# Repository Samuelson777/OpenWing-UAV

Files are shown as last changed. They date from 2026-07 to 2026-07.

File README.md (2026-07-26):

# OpenWing-UAV

**An open, parametric, multidisciplinary UAV-wing engineering project integrating CAD, CAM, aerodynamics, structural simulation, optimisation, prototype validation, automation, and an interactive 3D web application.**

**Author:** Samuelson G
**Current development stage:** Version 0.9 digital thread
**Target release:** Version 1.0 reproducible engineering baseline







---

## Table of Contents

* [Project Overview](#project-overview)
* [Project Objectives](#project-objectives)
* [Baseline Wing Specification](#baseline-wing-specification)
* [Key Features](#key-features)
* [Development History](#development-history)
* [Engineering Workflow](#engineering-workflow)
* [CAD and Structural Architecture](#cad-and-structural-architecture)
* [Aerodynamic Analysis](#aerodynamic-analysis)
* [Structural Simulation](#structural-simulation)
* [Optimisation](#optimisation)
* [Prototype Validation](#prototype-validation)
* [Live 3D Application](#live-3d-application)
* [Tutorial Drawings](#tutorial-drawings)
* [Repository Structure](#repository-structure)
* [Available File Formats](#available-file-formats)
* [Software Requirements](#software-requirements)
* [Getting Started](#getting-started)
* [Running the GitHub Pages App](#running-the-github-pages-app)
* [SOLIDWORKS 2023 Workflow](#solidworks-2023-workflow)
* [OpenVSP Workflow](#openvsp-workflow)
* [Python Automation](#python-automation)
* [Validation and Reproducibility](#validation-and-reproducibility)
* [Known Limitations](#known-limitations)
* [Project Status](#project-status)
* [Conclusion](#conclusion)
* [Future Enhancements](#future-enhancements)
* [Roadmap](#roadmap)
* [Safety Notice](#safety-notice)
* [Contributing](#contributing)
* [Citation](#citation)
* [License](#license)
* [Author](#author)

---

## Project Overview

OpenWing-UAV is an open-source engineering project focused on the complete digital development of a modular uncrewed-aircraft wing.

The project begins with a parametric aerodynamic layout and progressively integrates:

* Airfoil generation
* Wing planform design
* Dihedral and washout
* Internal spars and ribs
* Modular wing-joiner architecture
* Aileron and servo installation
* CAD and neutral-file generation
* CAM preparation
* OpenVSP and aerodynamic modelling
* Static structural analysis
* Root-joint and contact analysis
* Modal and buckling studies
* Fatigue and nonlinear-analysis planning
* Multidisciplinary optimisation
* Prototype proof and ultimate testing
* FEA-to-experiment correlation
* Repository automation
* Interactive browser-based 3D visualisation

The project is intended to demonstrate a complete aerospace engineering workflow that can be developed on a home PC and shared through an open-source GitHub repository.

---

## Project Objectives

The primary objectives of OpenWing-UAV are to:

1. Develop a modular UAV wing using a traceable parametric design process.
2. Connect aerodynamic geometry with internal structural architecture.
3. Produce reviewable CAD, neutral geometry, drawings, and manufacturing files.
4. Transfer aerodynamic loads into structural simulation cases.
5. Evaluate strength, displacement, buckling, vibration, joints, and control-system loads.
6. Optimise the design for mass, stiffness, stability, and manufacturability.
7. Define a safe and measurable physical-validation programme.
8. Automate repository validation, manifests, dashboards, and documentation.
9. Present the entire project through an interactive GitHub Pages application.
10. Establish a reusable framework for future UAV and aerospace projects.

---

## Baseline Wing Specification

| Parameter | Value |
| --- | ---: |
| Aircraft mass | 2.5 kg |
| Full wing span | 1,200 mm |
| Semi-span | 600 mm |
| Root chord | 240 mm |
| Tip chord | 160 mm |
| Wing area | 0.240 m² |
| Aspect ratio | 6.0 |
| Taper ratio | 0.667 |
| Airfoil | NACA 4412 |
| Dihedral | 3° per half-wing |
| Midspan washout | −1° |
| Tip washout | −2° |
| Cruise speed | 15 m/s |
| Positive limit load | +3.5 g |
| Negative limit load | −1.5 g |
| Ultimate load factor | 1.5 |
| Positive ultimate half-wing load | 64.356 N |
| Negative ultimate half-wing load | 27.581 N |

### Coordinate System

The primary SOLIDWORKS coordinate convention is:

```text
X-axis: spanwise
Y-axis: chordwise
Z-axis: vertical
Root plane: X = 0
```

---

## Key Features

### Parametric Geometry

* NACA 4412 airfoil generation
* Root, midspan, and tip airfoil profiles
* Tapered wing planform
* Equation-driven chord variation
* 3° dihedral
* Progressive washout
* Quarter-chord twist reference
* Configurable span, chord, and structural dimensions

### Internal Structure

* Main spar at approximately 30% chord
* Rear spar at approximately 70% chord
* Upper and lower spar caps
* Multiple structural rib stations
* Root support ribs
* Root web doubler
* Joiner box
* Rear anti-rotation pin
* Skin shell
* Servo bay
* Wiring channel
* Removable tip architecture

### Control System

* Outboard aileron
* Three hinge stations
* Servo tray
* Servo-arm and control-horn relationship
* Pushrod load calculations
* Positive and negative control deflections
* Servo-stall structural load case

### Engineering Validation

* Positive ultimate load case
* Negative ultimate load case
* Gust-load screening
* Ground-handling loads
* Tip torsion
* Local skin-pressure loads
* Root contact and bearing studies
* Modal analysis
* Buckling analysis
* Fatigue planning
* Nonlinear post-buckling sensitivity
* Aileron, hinge, and servo validation

---

## Development History

### Version 0.1 — Parametric Wing Foundation

* Established project repository
* Defined baseline aircraft and wing requirements
* Generated NACA 4412 airfoil coordinates
* Created root, midspan, and tip profiles
* Established coordinate systems and modelling conventions

### Version 0.2 — External Wing Geometry

* Created wing stations
* Applied taper, dihedral, and washout
* Constructed guide curves
* Generated boundary surfaces
* Formed the aerodynamic wing envelope

### Version 0.3 — Internal Structure and Assembly

* Added main and rear spars
* Added spar caps
* Defined rib stations
* Added root support structure
* Created joiner and anti-rotation-pin architecture
* Added servo bay, hinges, wiring channel, and aileron

### Version 0.4 — Drawings and Manufacturing Preparation

* Produced manufacturing drawings
* Prepared rib and spar DXF profiles
* Developed joiner CAM concepts
* Added additive-manufacturing components
* Prepared STEP, STL, and 3MF outputs
* Added assembly and manufacturing documentation

### Version 0.5 — Aerodynamic Analysis

* Defined OpenVSP wing geometry
* Prepared VSPAERO analysis workflow
* Developed angle-of-attack sweeps
* Generated spanwise aerodynamic loads
* Added aileron-effectiveness studies
* Added XFOIL airfoil-polars workflow
* Created preliminary performance envelopes

### Version 0.6 — Structural Multiphysics Validation

* Positive and negative static analyses
* Mesh-convergence planning
* Root-interface validation
* Modal analysis
* Buckling analysis
* Rotating-excitation comparison
* Gust and handling load cases
* Fatigue mission-spectrum templates
* Aileron, hinge, and servo analysis
* Nonlinear post-buckling planning

### Version 0.7 — Optimisation and Trade Studies

* Defined design variables
* Created goals and constraints
* Separated beam, skin/rib, and root optimisation
* Added lightweight, balanced, and high-stiffness candidates
* Developed Pareto-ranking workflow
* Added manufacturing-complexity scoring
* Added uncertainty and robustness studies

### Version 0.8 — Prototype Validation

* Defined material-coupon tests
* Created spar and root-joint test plans
* Added aileron and servo tests
* Developed positive and negative proof-load procedures
* Developed sacrificial ultimate-load procedures
* Added modal-impact testing
* Added FEA-to-experiment correlation templates
* Added controlled model-updating procedures

### Version 0.9 — Digital Thread and Automation

* Created GitHub-ready repository structure
* Added CSV schema validation
* Added automated repository checking
* Added SHA-256 release manifests
* Added GitHub Actions workflows
* Added a responsive live 3D GitHub Pages application
* Added interactive aerodynamic, structural, and manufacturing views
* Added project dashboards and downloadable assets

---

## Engineering Workflow

The project follows this connected workflow:

```text
Requirements
    ↓
Parametric airfoil and planform
    ↓
External aerodynamic geometry
    ↓
Internal spars, ribs, skin, and joints
    ↓
Control-system integration
    ↓
Manufacturing drawings and neutral exports
    ↓
Aerodynamic analysis
    ↓
Structural simulation
    ↓
Optimisation
    ↓
Prototype testing
    ↓
FEA-to-test correlation
    ↓
Controlled model update
    ↓
Reproducible engineering release
```

---

## CAD and Structural Architecture

### Airfoil Stations

| Station | Spanwise position |  Chord | Dihedral rise | Twist |
| --- | ---: | -----: | ---: | ----: |
| Root | 0 mm | 240 mm | 0 mm | 0° |
| Midspan | 300 mm | 200 mm | 15.72 mm | −1° |
| Tip | 600 mm | 160 mm | 31.45 mm | −2° |

### Rib Stations

The baseline rib architecture uses stations near:

```text
0, 25, 75, 150, 225, 300, 330, 390, 450, 510, 570, 600 mm
```

### Spar Dimensions

| Component | Baseline dimension |
| --- | ---: |
| Main spar web | 1.5 mm |
| Rear spar web | 1.2 mm |
| Main spar caps | 6 × 3 mm |
| Rear spar caps | 4 × 2 mm |
| Standard ribs | 2.0 mm |
| Root ribs | 3.0 mm |
| Aileron boundary ribs | 2.5 mm |
| Wing skin | 1.0 mm |
| Aileron skin | 0.8 mm |

### Joiner System

| Component | Baseline dimension |
| --- | ---: |
| Joiner blade | 18 × 4 mm |
| Insertion length | 150 mm per half-wing |
| Full joiner length | 300 mm |
| Rear pin diameter  | 6 mm |
| Rear-pin insertion |  60 mm per half-wing |
| Joiner clearance | 0.20 mm nominal |

---

## Aerodynamic Analysis

The aerodynamic workflow includes:

* NACA 4412 profile generation
* OpenVSP geometry construction
* VSPAERO lifting-surface analysis
* Angle-of-attack sweeps
* Spanwise lift-distribution export
* Cruise-load mapping
* Aileron-effectiveness assessment
* XFOIL low-Reynolds-number polar generation
* Preliminary stall and performance estimation

Reference aerodynamic outputs include:

```text
OWU_LiftingLine_AlphaSweep.csv
OWU_LiftingLine_Cruise_SpanLoads.csv
```

The included lifting-line and potential-flow results are preliminary engineering references. They do not replace viscous CFD, wind-tunnel testing, or flight-test correlation.

---

## Structural Simulation

The structural workflow includes:

### Static Studies

* Positive ultimate manoeuvre
* Negative ultimate manoeuvre
* Positive gust
* Negative gust
* Wingtip handling
* Wingtip torsion
* Servo stall
* Aileron hinge moment
* Local skin pressure

### Local Studies

* Root joiner
* Joiner box
* Rear pin
* Adhesive interfaces
* Spar-cap and web transitions
* Hinge pins and lugs
* Servo tray and mounting bosses

### Dynamic Studies

* Unloaded modal analysis
* Prestressed modal analysis
* Bending and torsional mode classification
* Motor and propeller excitation mapping
* Blade-pass-frequency comparison

### Stability Studies

* Positive global buckling
* Negative global buckling
* Upper-skin local buckling
* Lower-skin local buckling
* Main-web buckling
* Rear-web buckling
* Imperfection sensitivity
* Nonlinear post-buckling response

Reference neutral results include:

```text
OWU_BeamFEA_PositiveUltimate.csv
OWU_BeamFEA_NegativeUltimate.csv
OWU_BeamFEA_Modal.csv
OWU_BeamFEA_PositiveUltimate.vtk
OWU_Equivalent_Wing_Beam.inp
```

These reference results are based on simplified neutral models and are not presented as completed SOLIDWORKS Simulation certification results.

---

## Optimisation

The Version 0.7 optimisation workflow divides the problem into manageable studies.

### Beam Sizing

Variables include:

* Main-web thickness
* Main-cap width
* Main-cap thickness
* Rear-web thickness
* Rear-cap width
* Rear-cap thickness

### Skin and Rib Stability

Variables include:

* Skin thickness
* Standard rib thickness
* Sparse, baseline, or dense rib layout

### Root and Joiner Sizing

Variables include:

* Joiner height
* Joiner thickness
* Joiner-box wall thickness
* Root-doubler length
* Root-doubler thickness

### Candidate Designs

Three principal candidate families are considered:

* Lightweight
* Balanced
* High-stiffness

### Optimisation Criteria

* Minimum mass
* Tip displacement
* Tip twist
* Spar strength
* Joiner strength
* Composite failure index
* Buckling load factor
* First bending frequency
* First torsional frequency
* Manufacturing complexity
* CAD rebuild success
* Uncertainty sensitivity

A Python ranking script identifies feasible and Pareto-optimal candidates.

---

## Prototype Validation

The planned physical-validation programme includes:

### Material Tests

* Skin laminate coupons
* Spar-cap coupons
* Plywood and web coupons
* Adhesive lap joints
* Printed-material orientation tests
* Hinge-bearing coupons

### Subcomponent Tests

* Main-spar four-point bending
* Root-joiner bending and torsion
* Aileron and hinge loading
* Servo-stall testing
* Hinge-cycle testing

### Full-Wing Tests

| Test | Half-wing target |
| --- | ---: |
| Positive limit proof | 42.904 N |
| Negative limit proof | 18.387 N |
| Positive ultimate | 64.356 N |
| Negative ultimate | 27.581 N |

### Modal Testing

* Impact-hammer excitation
* Accelerometer measurements
* Frequency-response functions
* First bending mode
* First torsional mode
* Damping estimates
* FEA frequency correlation

### Correlation Targets

| Measurement | Initial target |
| --- | ---: |
| Tip displacement | ≤10% error |
| Midspan displacement | ≤10% error |
| Spar-cap strain | ≤15% error |
| Tip twist | ≤15% error |
| Root rotation | ≤15% error |
| First bending frequency | ≤5% error |
| First torsional frequency | ≤7% error |

These are project-level correlation targets, not regulatory requirements.

---

## Live 3D Application

The project includes a standalone GitHub Pages application built with HTML, CSS, and JavaScript.

### Features

* Interactive 3D wing model
* Orbit, pan, and zoom
* Isometric, front, and top views
* Version timeline from v0.1 to v0.9
* External aerodynamic geometry
* Internal rib and spar structure
* Joiner and root-system visualisation
* Aileron and servo views
* Aerodynamic span-load vectors
* Structural deformation display
* Modal animation
* Optimisation comparison
* Prototype-test visualisation
* Digital-thread dashboard
* Screenshot export
* Responsive mobile layout
* Software-rendered fallback where WebGL is unavailable

### GitHub Pages Deployment

Upload the application files to the repository root or `/docs` directory.

Then configure:

```text
Repository Settings
→ Pages
→ Source: GitHub Actions
```

or:

```text
Repository Settings
→ Pages
→ Deploy from a branch
→ Branch: main
→ Folder: /docs
```

---

## Tutorial Drawings

The project includes a full A3 landscape tutorial drawing manual.

The drawing set covers:

* General arrangement
* Half-wing planform
* Dihedral and washout
* Root, midspan, and tip sections
* Structural architecture
* Rib profiles
* Main and rear spars
* Joiner and rear pin
* Aileron and hinges
* Servo installation
* Wingtip assembly
* Skin installation
* Adhesive sequence
* Manufacturing plan
* SOLIDWORKS modelling workflow
* Simulation setup
* Proof-load test fixture
* Final inspection checklist

Suggested file:

```text
OpenWing-UAV-Full-Tutorial-Drawings.pdf
```

---

## Repository Structure

```text
OpenWing-UAV/
├── .github/
│   ├── workflows/
│   ├── ISSUE_TEMPLATE/
│   └── PULL_REQUEST_TEMPLATE.md
│
├── cad/
│   ├── native-solidworks/
│   │   ├── parts/
│   │   ├── assemblies/
│   │   └── drawings/
│   ├── neutral/
│   │   ├── step/
│   │   ├── stl/
│   │   └── 3mf/
│   └── dxf/
│
├── cam/
│   ├── cnc/
│   ├── additive/
│   ├── fixtures/
│   └── setup-sheets/
│
├── simulation/
│   ├── openvsp/
│   ├── vspaero/
│   ├── xfoil/
│   ├── solidworks-fea/
│   ├── neutral-fea/
│   └── load-cases/
│
├── optimisation/
│   ├── design-variables/
│   ├── candidates/
│   ├── results/
│   └── scripts/
│
├── prototype/
│   ├── material-coupons/
│   ├── subcomponent-tests/
│   ├── proof-tests/
│   ├── ultimate-tests/
│   ├── modal-tests/
│   └── correlation/
│
├── data/
│   ├── templates/
│   └── results/
│
├── drawings/
│   ├── tutorial/
│   ├── manufacturing/
│   └── inspection/
│
├── docs/
│   ├── index.html
│   ├── assets/
│   └── downloads/
│
├── scripts/
│   ├── validation/
│   ├── geometry/
│   ├── simulation/
│   ├── optimisation/
│   └── release/
│
├── release/
├── media/
├── schemas/
├── README.md
├── ROADMAP.md
├── CHANGELOG.md
├── CONTRIBUTING.md
├── CITATION.cff
├── SECURITY.md
└── LICENSE
```

---

## Available File Formats

The project may contain or generate:

### CAD and Manufacturing

```text
.SLDPRT
.SLDASM
.SLDDRW
.STEP
.STP
.STL
.3MF
.DXF
.SVG
.PDF
```

### Aerodynamic and Simulation

```text
.vsp3
.vspscript
.inp
.vtk
.csv
.json
.txt
```

### Automation and Web

```text
.py
.js
.html
.css
.yml
.yaml
.bat
.md
```

### Important Format Note

STEP, STL, and 3MF files contain transferable geometry but do not preserve original SOLIDWORKS parametric feature history.

Native SOLIDWORKS files should be generated and saved using an installed copy of SOLIDWORKS 2023.

---

## Software Requirements

Depending on the selected workflow:

* SOLIDWORKS 2023
* SOLIDWORKS Simulation
* OpenVSP
* VSPAERO
* XFOIL
* Python 3.11 or newer
* Git
* Git LFS
* Modern web browser
* Optional CNC CAM software
* Optional slicing software for 3D printing

### Python Packages

Most repository-automation scripts use the Python standard library.

The SOLIDWORKS automation workflow may additionally require:

```bash
pip install pywin32
```

---

## Getting Started

### 1. Clone the Repository

```bash
git clone https://github.com/OWNER/OpenWing-UAV.git
cd OpenWing-UAV
```

Replace `OWNER` with the GitHub username or organisation name.

### 2. Install Git LFS

```bash
git lfs install
git lfs pull
```

### 3. Validate the Repository

```bash
python scripts/validate_repository.py
```

### 4. Generate Dashboard Data

```bash
python scripts/generate_dashboard_data.py
```

### 5. Generate the Release Manifest

```bash
python scripts/build_release_manifest.py
```

### 6. Run All Automation

```bash
make all
```

---

## Running the GitHub Pages App

The application does not require a JavaScript build system.

### Local Use

Open:

```text
index.html
```

in a modern browser.

For browsers that restrict local file loading, run a local HTTP server:

```bash
python -m http.server 8000
```

Then visit:

```text
http://localhost:8000
```

### GitHub Pages

Push the website to GitHub and enable Pages from the repository settings.

---

## SOLIDWORKS 2023 Workflow

The repository includes a Windows automation package for importing STEP files into SOLIDWORKS 2023.

The workflow can:

1. Open STEP models.
2. Run import diagnostics.
3. Save imported parts as `.SLDPRT`.
4. Build assemblies as `.SLDASM`.
5. Create third-angle drawings as `.SLDDRW`.
6. Export drawing PDFs.
7. Produce conversion logs.

Example launcher:

```text
RUN_SOLIDWORKS_2023_CONVERTER.bat
```

The conversion creates genuine SOLIDWORKS files only when executed on a Windows PC with SOLIDWORKS 2023 installed.

Imported STEP files become native imported-body features. They do not automatically recover the original sketches, equations, loft history, mates, or design intent.

---

## OpenVSP Workflow

The OpenVSP workflow includes:

* Python model generator
* AngelScript generator
* Wing planform configuration
* NACA 4412 section definition
* Dihedral and twist
* Native `.vsp3` generation
* STEP, STL, and DXF exports

Example generator files:

```text
generate_openwing_vsp.py
generate_openwing.vspscript
RUN_OPENVSP_GENERATOR.bat
```

---

## Python Automation

The project includes scripts for:

* NACA 4412 profile generation
* Root, midspan, and tip coordinate generation
* Load-band scaling
* Gust-load preparation
* Rotating-excitation mapping
* Candidate ranking
* FEA-to-test error calculation
* CSV schema checking
* Repository validation
* Dashboard-data generation
* Release-manifest generation
* SHA-256 file hashing
* SOLIDWORKS automation
* OpenVSP automation

---

## Validation and Reproducibility

The project uses the following reproducibility principles:

* Every released model receives a revision.
* Baseline inputs are never silently overwritten.
* Raw solver data remain separate from processed results.
* Numerical values include units and source descriptions.
* Failed studies are retained and documented.
* CAD, manufacturing, and analysis files remain revision-aligned.
* Release files receive SHA-256 hashes.
* CSV templates use controlled headers.
* GitHub Actions checks repository structure.
* Generated dashboard files are compared with committed versions.
* Preliminary models are not presented as certification evidence.

### Release Manifest

Run:

```bash
python scripts/build_release_manifest.py
```

This generates:

```text
release/manifest.csv
release/manifest.json
```

---

## Known Limitations

The current project has the following limitations:

1. The wing has not yet completed a full physical proof and ultimate test programme.
2. Material properties require coupon testing using the actual manufacturing process.
3. Reference aerodynamic results are not equivalent to validated viscous CFD or wind-tunnel data.
4. Neutral beam results are simplified and are not final detailed SOLIDWORKS Simulation results.
5. Imported STEP models do not preserve full parametric SOLIDWORKS history.
6. Generic CAM files must not be used without machine-specific verification.
7. Modal analysis alone does not establish flutter safety.
8. Potential-flow analysis does not accurately predict separated stall behaviour.
9. Complete-aircraft stability, propulsion, energy, and flight-control integration remain future work.
10. The design is not certified for flight or commercial operation.

---

## Project Status

| Workstream | Status |
| --- | --- |
| Baseline requirements | Complete |
| Parametric airfoil profiles | Complete |
| External wing geometry | Complete |
| Structural architecture | Complete |
| Neutral CAD generation | Complete |
| Tutorial drawings | Complete |
| Live 3D web application | Complete |
| Aerodynamic workflow | Complete |
| Reference aerodynamic outputs | Available |
| Structural simulation workflow | Complete |
| Neutral structural outputs | Available |
| Optimisation workflow | Complete |
| Prototype-test planning | Complete |
| Native SOLIDWORKS conversion workflow | Available |
| OpenVSP native generation workflow | Available |
| Material coupon testing | Not completed |
| Full detailed FEA validation | Not completed |
| Physical proof testing | Not completed |
| Modal test correlation | Not completed |
| Complete-aircraft integration | Not completed |
| Flight readiness | Not claimed |

---

## Conclusion

The OpenWing-UAV project demonstrates a complete, traceable, and multidisciplinary workflow for developing a modular uncrewed-aircraft wing from an initial aerodynamic concept to a digitally documented engineering system.

Beginning with the Version 0.1 parametric wing definition, the project progressively integrated airfoil generation, planform geometry, dihedral, washout, structural architecture, control surfaces, modular joiner systems, manufacturing preparation, aerodynamic assessment, structural simulation, optimisation, prototype-test planning, and repository automation through Version 0.9.

The baseline design uses a 1.2 m tapered wing with a NACA 4412 airfoil, 3° dihedral, −2° tip washout, internal spars and ribs, a removable joiner system, and an integrated aileron and servo arrangement. A consistent digital thread connects CAD geometry, manufacturing files, aerodynamic loads, structural load cases, modal and buckling studies, optimisation variables, test procedures, and project documentation.

A major strength of the project is that CAD, simulation, manufacturing, testing, and documentation are treated as connected engineering activities rather than isolated tasks. Aerodynamic loads feed structural studies, optimisation is constrained by strength and manufacturability, and physical tests are designed to correlate and improve the computational models.

The generated neutral CAD files, drawings, scripts, aerodynamic references, structural templates, optimisation tools, prototype-test plans, repository automation, and live 3D application provide a practical foundation for further development.

OpenWing-UAV therefore fulfils its purpose as an open-source aerospace engineering portfolio project. It demonstrates skills in parametric design, aerodynamics, structural mechanics, optimisation, digital manufacturing, experimental planning, software automation, technical documentation, data management, and interactive web development.

The current design should be regarded as a documented engineering prototype rather than a flight-certified aircraft component. Final flight-readiness decisions must follow physical material testing, detailed model validation, complete-aircraft integration, safety assessment, regulatory review, ground testing, and controlled flight testing.

---

## Future Enhancements

### 1. Fully Parametric Native SOLIDWORKS Models

Rebuild all imported neutral geometry as native SOLIDWORKS parts and assemblies using:

* Equation-driven sketches
* Design tables
* Parametric lofts
* Configurations
* Assembly mates
* Automated drawings
* BOM-linked custom properties
* Manufacturing configurations

This would preserve complete design intent and allow automatic resizing.

### 2. Higher-Fidelity Aerodynamics

Add:

* Viscous CFD
* Transition modelling
* Stall progression
* Propeller–wing interaction
* Control-surface gaps
* Ground effect
* Sideslip
* Unsteady gust response
* Wind-tunnel correlation
* Flight-pressure measurements

### 3. Composite Laminate Modelling

Define:

* Ply materials
* Ply orientations
* Stacking sequence
* Fibre volume fraction
* Cure process
* Core material
* Bond-line thickness
* Manufacturing tolerances

Apply composite failure criteria such as:

* Tsai–Wu
* Hashin
* Maximum stress
* Maximum strain
* Interlaminar shear
* Delamination screening

### 4. Detailed Joint and Adhesive Analysis

Improve:

* Joiner-box contact
* Adhesive peel modelling
* Cohesive-zone behaviour
* Pin bearing
* Clearance sensitivity
* Bolt preload
* Friction
* Progressive joint failure
* Root-rib bearing
* Hinge-lug fatigue

### 5. Aeroelasticity and Flutter

Add:

* Static divergence
* Control reversal
* Flutter-speed estimation
* Servo stiffness
* Hinge free play
* Mass balancing
* Gust response
* Motor-order excitation
* Propeller blade-pass excitation
* Aeroelastic model correlation

### 6. Complete-Aircraft Integration

Develop:

* Fuselage
* Tail surfaces
* Landing or launch system
* Propulsion
* Battery system
* Avionics
* Payload
* Cooling
* Wiring
* Maintenance access
* Complete mass properties
* Centre-of-gravity envelope

### 7. Propulsion and Energy Optimisation

Add:

* Motor selection
* Propeller matching
* Electronic speed controller sizing
* Battery sizing
* Endurance analysis
* Climb performance
* Thermal modelling
* Power reserve
* Voltage-drop analysis
* Vibration monitoring

### 8. Multidisciplinary Optimisation

Extend the current optimisation to include:

* Aerodynamic efficiency
* Structural mass
* Endurance
* Cost
* Manufacturing time
* Noise
* Reliability
* Stability
* Repairability

Possible methods include:

* Latin-hypercube sampling
* Genetic algorithms
* Bayesian optimisation
* Surrogate modelling
* Monte Carlo uncertainty analysis

### 9. Manufacturing Automation

Add:

* Validated machine-specific CNC files
* Post-processors
* Tool libraries
* Cutting layouts
* Material nesting
* Drill jigs
* Assembly fixtures
* Composite moulds
* Print profiles
* Inspection gauges
* Digital work instructions

### 10. Physical Prototype Testing

Complete:

* Material coupons
* Main-spar bending test
* Root-joiner test
* Hinge and servo tests
* Positive proof load
* Negative proof load
* Positive ultimate test
* Negative ultimate test
* Modal impact test
* FEA-to-test correlation

### 11. Hardware-in-the-Loop Testing

Integrate:

* Autopilot hardware
* Servos
* Sensors
* Communication links
* Telemetry
* Actuator limits
* Navigation software
* Failure handling
* Software-in-the-loop simulation
* Hardware-in-the-loop simulation

### 12. Flight-Test Programme

Create a controlled sequence for:

* Ground inspection
* Control checks
* Propulsion tests
* Restrained tests
* Initial low-risk flight
* Envelope expansion
* Endurance flights
* Gust testing
* Emergency-procedure validation
* Post-flight structural inspection

### 13. Safety and Regulatory Development

Add:

* Hazard analysis
* Failure-mode-and-effects analysis
* Operational risk assessment
* Maintenance intervals
* Inspection procedures
* Component life limits
* Lost-link logic
* Geofencing
* Emergency recovery
* Applicable regulatory requirements

### 14. Digital Twin

Connect real telemetry to the 3D model:

* Strain
* Vibration
* Temperature
* Battery condition
* Servo position
* Flight loads
* Fatigue accumulation
* Maintenance warnings
* Historical mission replay

### 15. Enhanced Web Application

Extend the GitHub Pages app with:

* glTF loading
* STEP-derived visual assets
* Exploded assemblies
* Section-cut tools
* Measurement tools
* Result contours
* Interactive plots
* Version comparisons
* Offline progressive-web-app installation
* Accessibility improvements

### 16. Automated Engineering Pipeline

Develop one controlled configuration file that can automatically generate:

* Airfoil profiles
* CAD parameters
* OpenVSP models
* Aerodynamic loads
* FEA inputs
* Optimisation scenarios
* Plots
* Drawings
* Documentation
* Website data
* Release manifests

### 17. Open Community Configurations

Allow contributors to submit:

* Alternative airfoils
* Different spans
* Different materials
* Alternative joiners
* Different propulsion systems
* New manufacturing processes
* Experimental results
* Additional analysis tools

All contributions should preserve common units, metadata, naming, licensing, and validation rules.

### 18. Version 1.0 Reproducible Release

Version 1.0 should contain:

* Final selected native CAD
* Released neutral CAD
* Manufacturing drawings
* Completed aerodynamic results
* Converged structural studies
* Material-property sources
* Prototype-test results
* Correlated FEA model
* Documented limitations
* Tagged release package
* Verified SHA-256 manifest

### 19. Complete Open UAV Platform

The long-term goal is to expand OpenWing-UAV into a complete modular uncrewed-aircraft development platform supporting:

* Aerospace education
* Environmental monitoring
* Mapping
* Research payloads
* Autonomous navigation
* Structural-health monitoring
* Comparative configuration studies
* Open and reproducible flight-test research

---

## Roadmap

```text
Version 1.0
Reproducible wing engineering release

Version 2.0
Complete aircraft integration

Version 3.0
Flight-test and telemetry digital thread
```

See [ROADMAP.md](ROADMAP.md) for the detailed roadmap.

---

## Safety Notice

This repository contains engineering geometry, structural calculations, test procedures, and manufacturing references.

Before manufacturing or testing:

* Verify all dimensions.
* Confirm material properties.
* Review machine settings.
* Simulate CAM outputs.
* Inspect imported CAD.
* Recalculate loads.
* Use calibrated instrumentation.
* Establish exclusion zones.
* Use remote loading for structural tests.
* Follow applicable UAV regulations.
* Obtain qualified engineering review where required.

Do not use generic NC or G-code directly on a machine without reviewing:

* Controller compatibility
* Units
* Coordinate system
* Tool length
* Feed rate
* Spindle speed
* Workholding
* Clearance
* Stock dimensions
* Emergency-stop procedure

This project does not provide certification, airworthiness approval, or permission to operate an aircraft.

---

## Contributing

Contributions are welcome in areas such as:

* CAD improvements
* Aerodynamics
* Structural analysis
* Materials
* Manufacturing
* Testing
* Automation
* Documentation
* Web development
* Data visualisation

Before submitting a pull request, include:

1. The problem or requirement.
2. The affected revision.
3. The changed assumptions.
4. Validation evidence.
5. Regenerated derived files.
6. Known limitations.

See [CONTRIBUTING.md](CONTRIBUTING.md).

---

## Citation

Citation metadata is provided in:

```text
CITATION.cff
```

Suggested citation:

```text
Samuelson G. OpenWing-UAV: An Open Parametric CAD, CAM,
Aerodynamic, Structural Validation, Optimisation, and Prototype
Testing Framework for a Modular Uncrewed-Aircraft Wing. 2026.
```

---

## License

The repository scaffold, scripts, and documentation are released under the MIT License unless otherwise stated.

See [LICENSE](https://github.com/Samuelson777/OpenWing-UAV/blob/main/LICENSE).

Before publishing third-party datasets or engineering files, confirm redistribution rights for:

* Airfoil data
* Material databases
* Standards
* CAD libraries
* Software-generated assets
* Test data
* Manufacturer specifications

---

## Author

**Samuelson G**

OpenWing-UAV is developed as an open-source aerospace engineering, research, automation, and portfolio project.

---

## Acknowledgement

This project uses concepts and workflows associated with:

* Parametric CAD
* OpenVSP
* VSPAERO
* XFOIL
* Finite-element analysis
* Composite structures
* Experimental modal analysis
* Multidisciplinary design optimisation
* GitHub Actions
* GitHub Pages
* Open engineering documentation

---

## Final Statement

OpenWing-UAV is not only a wing model. It is a complete engineering-development framework connecting requirements, geometry, analysis, manufacturing, testing, optimisation, documentation, and public communication in one traceable open-source project.

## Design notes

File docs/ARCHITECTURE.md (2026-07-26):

# Application architecture

- `index.html`: semantic application shell and accessible controls.
- `styles.css`: responsive desktop/mobile dashboard styling.
- `app.js`: minimal WebGL 2 renderer, camera, parametric geometry, analysis overlays and UI state.
- `data/app-data.js`: generated project data from CSV engineering outputs.
- `sw.js`: offline application-shell cache.
- `assets/downloads/`: downloadable engineering artefacts.

The application intentionally uses no npm build, framework, CDN or runtime dependency. GitHub Pages serves the files directly.

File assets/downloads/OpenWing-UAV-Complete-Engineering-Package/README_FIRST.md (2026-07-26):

# OpenWing-UAV Complete Engineering Package

This package combines all previously created project files with the newly generated engineering deliverables.

## Newly generated

- 32 watertight part geometries
- 35 AP203 faceted STEP files
- 35 STL files
- 35 3MF files
- 16 DXF drawings and SVG previews
- 13 generic, unverified NC files
- Right-wing and full-wing geometry assemblies
- Completed lifting-line aerodynamic result CSVs
- Completed equivalent beam-FEA static and modal results
- Neutral CalculiX/Abaqus-style input deck and VTK result
- OpenVSP scripts that generate the native `.vsp3` model and OpenVSP exports
- SOLIDWORKS COM automation that generates `.SLDPRT`, `.SLDASM`, and `.SLDDRW` files when run on Windows with SOLIDWORKS installed

## Remaining application-dependent outputs

Native SOLIDWORKS binaries and the native OpenVSP `.vsp3` file cannot be written without those installed applications. The package includes executable generator scripts for them rather than fake files. Native SOLIDWORKS Simulation databases and machine-approved G-code also require the licensed solver and actual machine/postprocessor.

Start with:

`02_GENERATED_ENGINEERING_FILES/08_DOCUMENTATION/README_FIRST.md`

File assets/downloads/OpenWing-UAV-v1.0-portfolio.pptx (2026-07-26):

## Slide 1

FINAL REPRODUCIBLE ENGINEERING RELEASE

OpenWing-UAV

A complete CAD · CAM · Aero · FEA · Optimisation · Prototype-validation digital thread for a modular UAV wing.

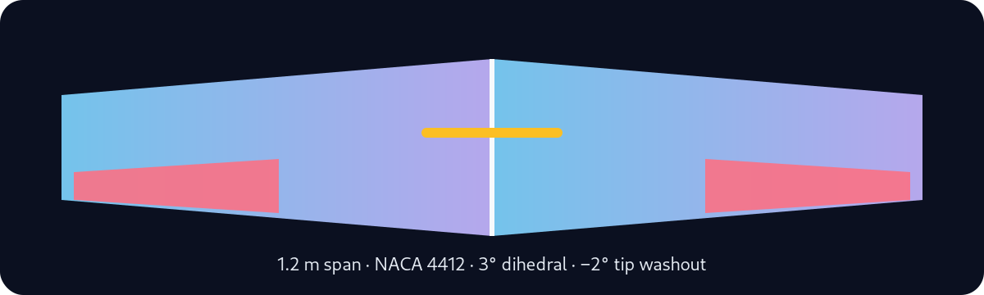
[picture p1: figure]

GitHub-ready v1.0 release framework

Home-PC feasible engineering workflow

Release gate: every claim links to evidence

Author: Samuelson G

OpenWing-UAV v1.0 · Samuelson G

01

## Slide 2

The portfolio challenge

Show credible aerospace CAD/CAM/CAE capability without needing a factory or wind tunnel.

Result: a project that demonstrates the full engineering loop, not only a CAD model.

Design depth

Parametric wing, aileron, spars, ribs, joiner, hinges and manufacturable parts.

1

Engineering proof

Loads, FEA, buckling, modal response, optimisation and test correlation.

2

Open-source credibility

Repository validation, data schemas, dashboards and release manifests.

3

OpenWing-UAV v1.0 · Samuelson G

02

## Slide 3

Digital thread architecture

Every output is linked to a source model, requirement, dataset or test.

No result is “final” unless its source data, units, coordinate system, revision, acceptance criterion and limitation are recorded.

CAD

Parametric wing

Aero

OpenVSP/XFOIL

Optimise

Pareto trades

Correlate

Model update

CAM

CNC + AM

FEA

Static + modal

Prototype

Proof + modal

Release

Manifest + site

Core rule

OpenWing-UAV v1.0 · Samuelson G

03

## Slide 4

Baseline wing specification

A compact UAV half-wing that is still rich enough for real engineering validation.

1.200 m

span

0.240 m²

area

NACA 4412

airfoil

3°

dihedral

−2°

tip washout

64.356 N

+ ultimate half-wing

27.581 N

− ultimate half-wing

6.0

aspect ratio

OpenWing-UAV v1.0 · Samuelson G

04

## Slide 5

Validation stack

The model becomes credible only when analysis and experiment agree within defined targets.

OpenVSP, VSPAERO, XFOIL, parasite drag, stall sensitivity

Static, contact, adhesive, modal, buckling, fatigue, nonlinear

Coupons, spar, root joiner, aileron, proof, ultimate, modal

Model updating, evidence matrix, independent validation case

Acceptance examples: reaction equilibrium ≤1%, displacement correlation ≤10%, first bending frequency error ≤5%, torsion ≤7%.

Aero loads

Structural FEA

Prototype tests

Correlation

OpenWing-UAV v1.0 · Samuelson G

05

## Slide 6

Repository automation

The project is packaged as a reviewable, reproducible GitHub repository.

Validated package: 71 repository files · engineering templates · GitHub Pages site · release framework

CSV schemas

Required columns for controlled evidence tables

Validation CI

Checks paths, config, CSV headers, Pages files and temp files

Dashboard data

Generates a JSON catalogue for the portfolio site

Release manifest

Creates SHA-256 hashes for every release artefact

Release gate

Blocks final claims until required evidence is complete

OpenWing-UAV v1.0 · Samuelson G

06

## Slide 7

v1.0 evidence gate

The final release separates “framework ready” from “engineering validated.”

Repository scaffold, website, validators, manifests, v1.0 checklists, release notes, presentation assets.

CAD baseline, solver outputs, coupon data, proof tests, modal results and correlated FEA model.

Only after every required matrix item points to reviewed evidence with traceable revision and units.

Honest release status is a feature: it shows discipline, not weakness.

Ready now

Requires evidence

Final claim

OpenWing-UAV v1.0 · Samuelson G

07

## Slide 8

Skills demonstrated

A single project covering the complete aerospace engineering workflow.

Portfolio takeaway: design thinking + simulation literacy + manufacturing realism + open-source discipline.

CAD

SolidWorks part, multibody, assembly, drawings

CAM

DXF, CNC routing, joiner machining, setup sheets

AM

STL/3MF, print orientation, fit coupons

Aero

OpenVSP/VSPAERO, XFOIL, performance envelope

FEA

Static, contact, buckling, modal, fatigue, nonlinear

Testing

Coupons, proof loads, modal hammer, correlation

Optimisation

Design studies, Pareto ranking, uncertainty

DevOps

GitHub Actions, Pages, manifests, schemas

OpenWing-UAV v1.0 · Samuelson G

08

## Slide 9

Path beyond v1.0

The repository is ready to become a real test-correlated engineering baseline.

Next action: upload the repository, replace OWNER placeholders, enable Pages, and begin filling the release evidence matrix.

v1.0

Populate evidence and tag reproducible release

v2.0

Integrate fuselage, empennage, propulsion and complete-aircraft stability

v3.0

Add flight-test data, telemetry processing and validated operating envelope

OpenWing-UAV v1.0 · Samuelson G

09

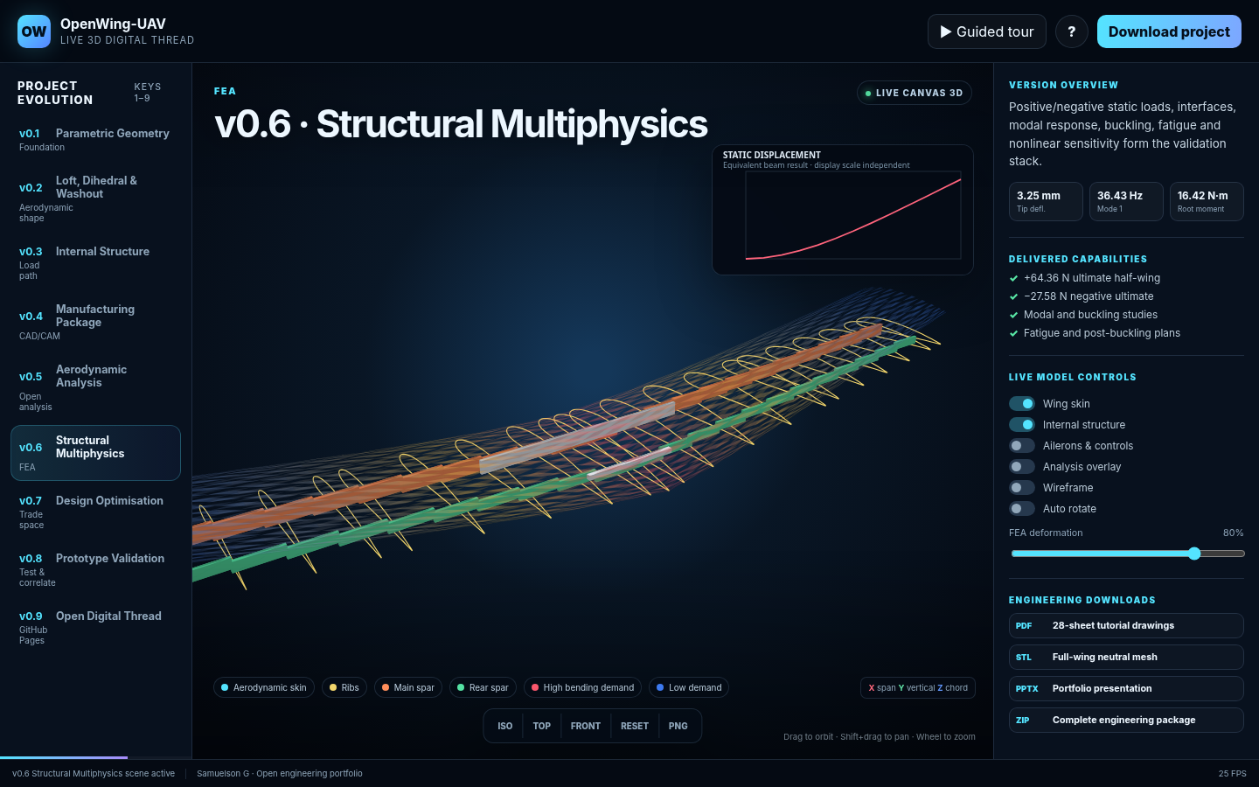
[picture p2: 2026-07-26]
assets/images/live-3d-preview.png

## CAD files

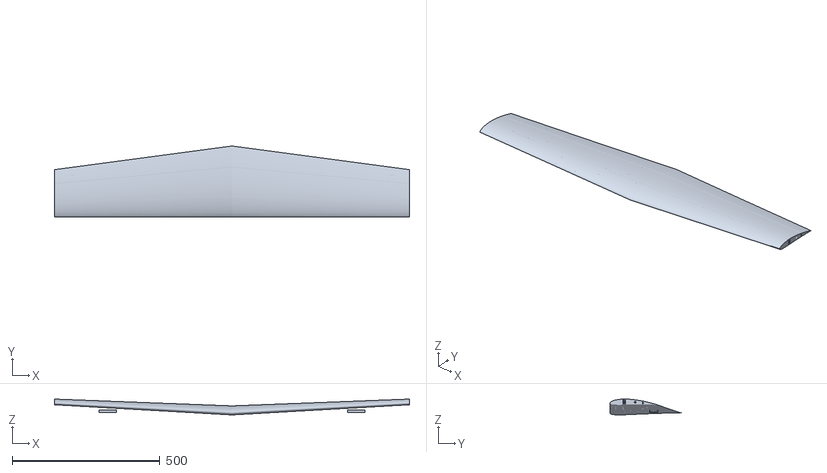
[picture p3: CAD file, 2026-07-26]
assets/downloads/OWU-1000_Full_Wing_Assembly.stl
1200.0 x 240.1 x 53.7

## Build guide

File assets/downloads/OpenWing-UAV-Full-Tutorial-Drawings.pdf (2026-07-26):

# OPENWING-UAV

# FULL TUTORIAL DRAWING MANUAL

Parametric CAD, internal structure, control system, assembly, simulation and prototype validation

# Author: SAMUELSON G

Drawing package revision A | Units: millimetres unless otherwise stated | July 2026

# Drawing index and tutorial sequence

Sheet | Drawing | Title | Purpose
01 | OWU-TUT-000 | Cover | Project identity
02 | OWU-TUT-001 | Drawing index | Navigation and conventions
03 | OWU-TUT-002 | Project baseline | Key design inputs
04 | OWU-TUT-003 | Coordinate system | SolidWorks reference setup
05 | OWU-TUT-100 | Full-wing general arrangement | Primary dimensions
06 | OWU-TUT-110 | Right half-wing layout | Stations, spars and aileron
07 | OWU-TUT-120 | Dihedral and washout | Front/section geometry
08 | OWU-TUT-130 | Airfoil sections | Root, mid and tip profiles
09 | OWU-TUT-200 | Internal structure | Exploded structural architecture
10 | OWU-TUT-210 | Root rib | Root slots and systems
11 | OWU-TUT-211 | Standard rib | Typical rib manufacture
12 | OWU-TUT-212 | Servo-bay rib | Control installation clearance
13 | OWU-TUT-220 | Spar system | Web and cap sizing
14 | OWU-TUT-230 | V-joiner and root box | Removable wing interface
15 | OWU-TUT-231 | Rear anti-rotation pin | Secondary root restraint
16 | OWU-TUT-300 | Aileron geometry | Cut, hinge and gaps
17 | OWU-TUT-310 | Hinge fitting | Pin, barrel and lugs
18 | OWU-TUT-320 | Servo bay and linkage | Actuator installation
19 | OWU-TUT-330 | Wingtip cap | Removable 50 mm tip
20 | OWU-TUT-400 | Skin and bonding | Shells and adhesive sequence
21 | OWU-TUT-410 | Assembly sequence A | Spars, ribs and root
22 | OWU-TUT-411 | Assembly sequence B | Skin, controls and closure
23 | OWU-TUT-500 | SolidWorks modelling workflow | Feature-by-feature tutorial
24 | OWU-TUT-600 | Static simulation setup | Loads, restraints and mesh
25 | OWU-TUT-610 | Modal and buckling setup | Dynamic and stability studies
26 | OWU-TUT-700 | Prototype proof-load fixture | Distributed test setup
27 | OWU-TUT-800 | Manufacturing and BOM | Parts, materials and processes
28 | OWU-TUT-900 | Inspection and release | Final checklist

## OPENWING-UAV

Drawing index

Tutorial drawing - dimensions in mm - verify before manufacture

DRAWING | SHEET
OWU-TUT-001 | 2/28
SCALE NTS | REV A
Educational engineering package. Not a certification or flight-release drawing.

# Project baseline and design intent

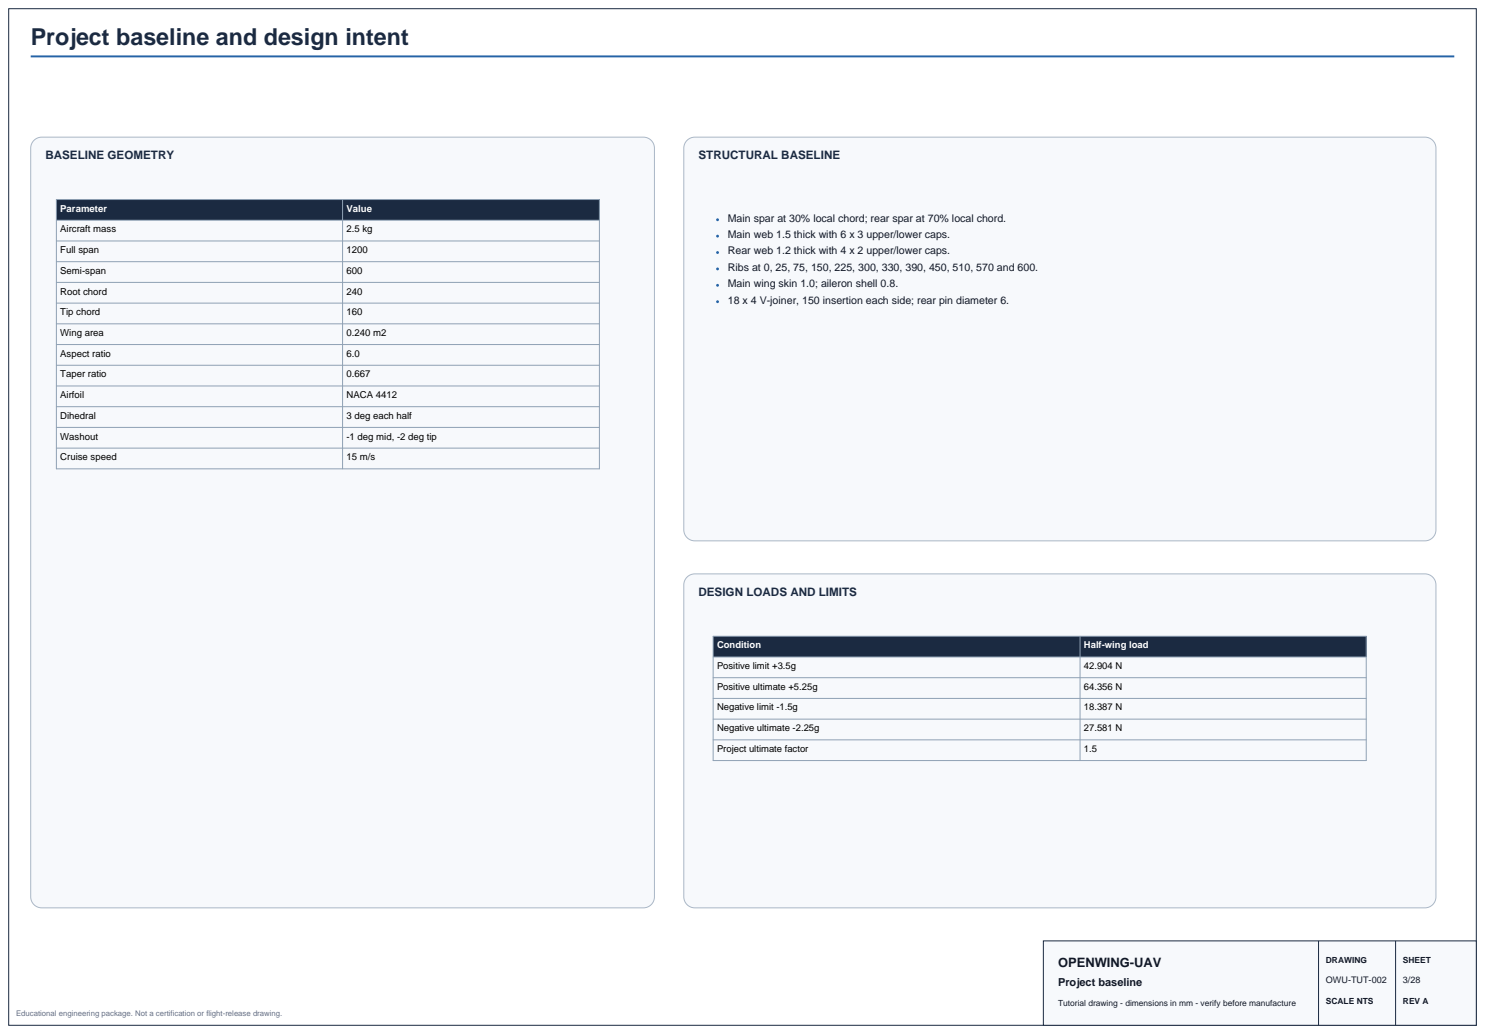
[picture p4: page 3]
BASELINE GEOMETRY; STRUCTURAL BASELINE; OPENWING-UAV; Project baseline; DRAWING; SHEET; OWU-TUT-002

Parameter | Value
Aircraft mass | 2.5 kg
Full span | 1200
Semi-span | 600
Root chord | 240
Tip chord | 160
Wing area | 0.240 m2
Aspect ratio | 6.0
Taper ratio | 0.667
Airfoil | NACA 4412
Dihedral | 3 deg each half
Washout | -1 deg mid, -2 deg tip
Cruise speed | 15 m/s

Main spar at 30% local chord; rear spar at 70% local chord.
Main web 1.5 thick with 6 x 3 upper/lower caps.
Rear web 1.2 thick with 4 x 2 upper/lower caps.
Ribs at 0, 25, 75, 150, 225, 300, 330, 390, 450, 510, 570 and 600.
Main wing skin 1.0; aileron shell 0.8.
18 x 4 V-joiner, 150 insertion each side; rear pin diameter 6.

DESIGN LOADS AND LIMITS

Condition | Half-wing load
Positive limit +3.5g | 42.904 N
Positive ultimate +5.25g | 64.356 N
Negative limit -1.5g | 18.387 N
Negative ultimate -2.25g | 27.581 N
Project ultimate factor | 1.5

# SolidWorks coordinate system and master reference planes

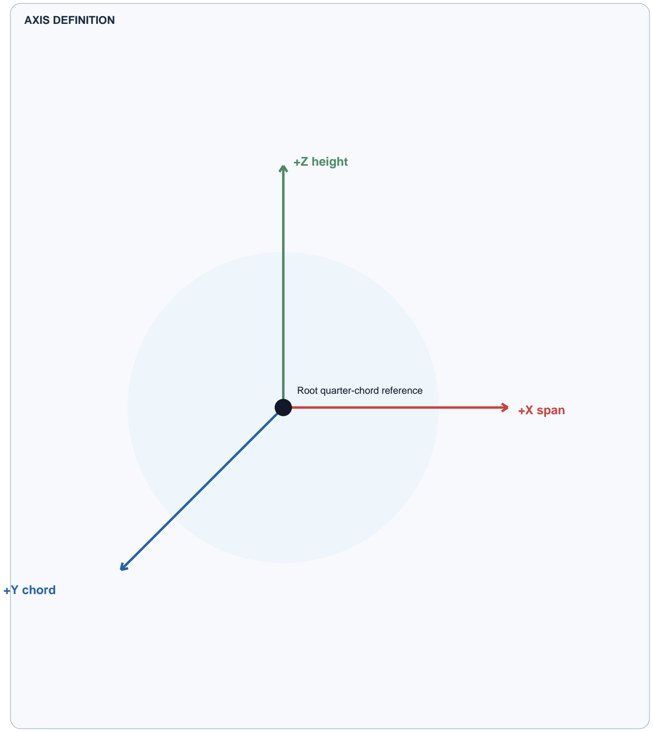
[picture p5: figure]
AXIS DEFINITION; +X span; +Z height; +Y chord; Root quarter-chord reference

### MASTER REFERENCES

Root plane: X = 0 symmetry and joiner centre.
Midspan plane: X = 300, dihedral rise 15.722, twist -1 deg.
Tip plane: X = 600, dihedral rise 31.445, twist -2 deg.
All twist rotations are about each section quarter-chord point.
Chord direction +Y points from leading edge toward trailing edge. Use named axes AX_SPAN, AX_AILERON_HINGE and AX_JOINER.

### SOLIDWORKS SETUP TUTORIAL

1. Create a new metric part and save immediately.
2. Insert planes offset 300 and 600 from the root plane.
3. Create quarter-chord sketch points on all station planes.
4. Apply 3 deg dihedral through Z offsets, then apply twist.
5. Lock station sketches to global variables before lofting.

## OPENWING-UAV

Coordinate system

DRAWING | SHEET
OWU-TUT-003 | 4/28

# Full-wing general arrangement

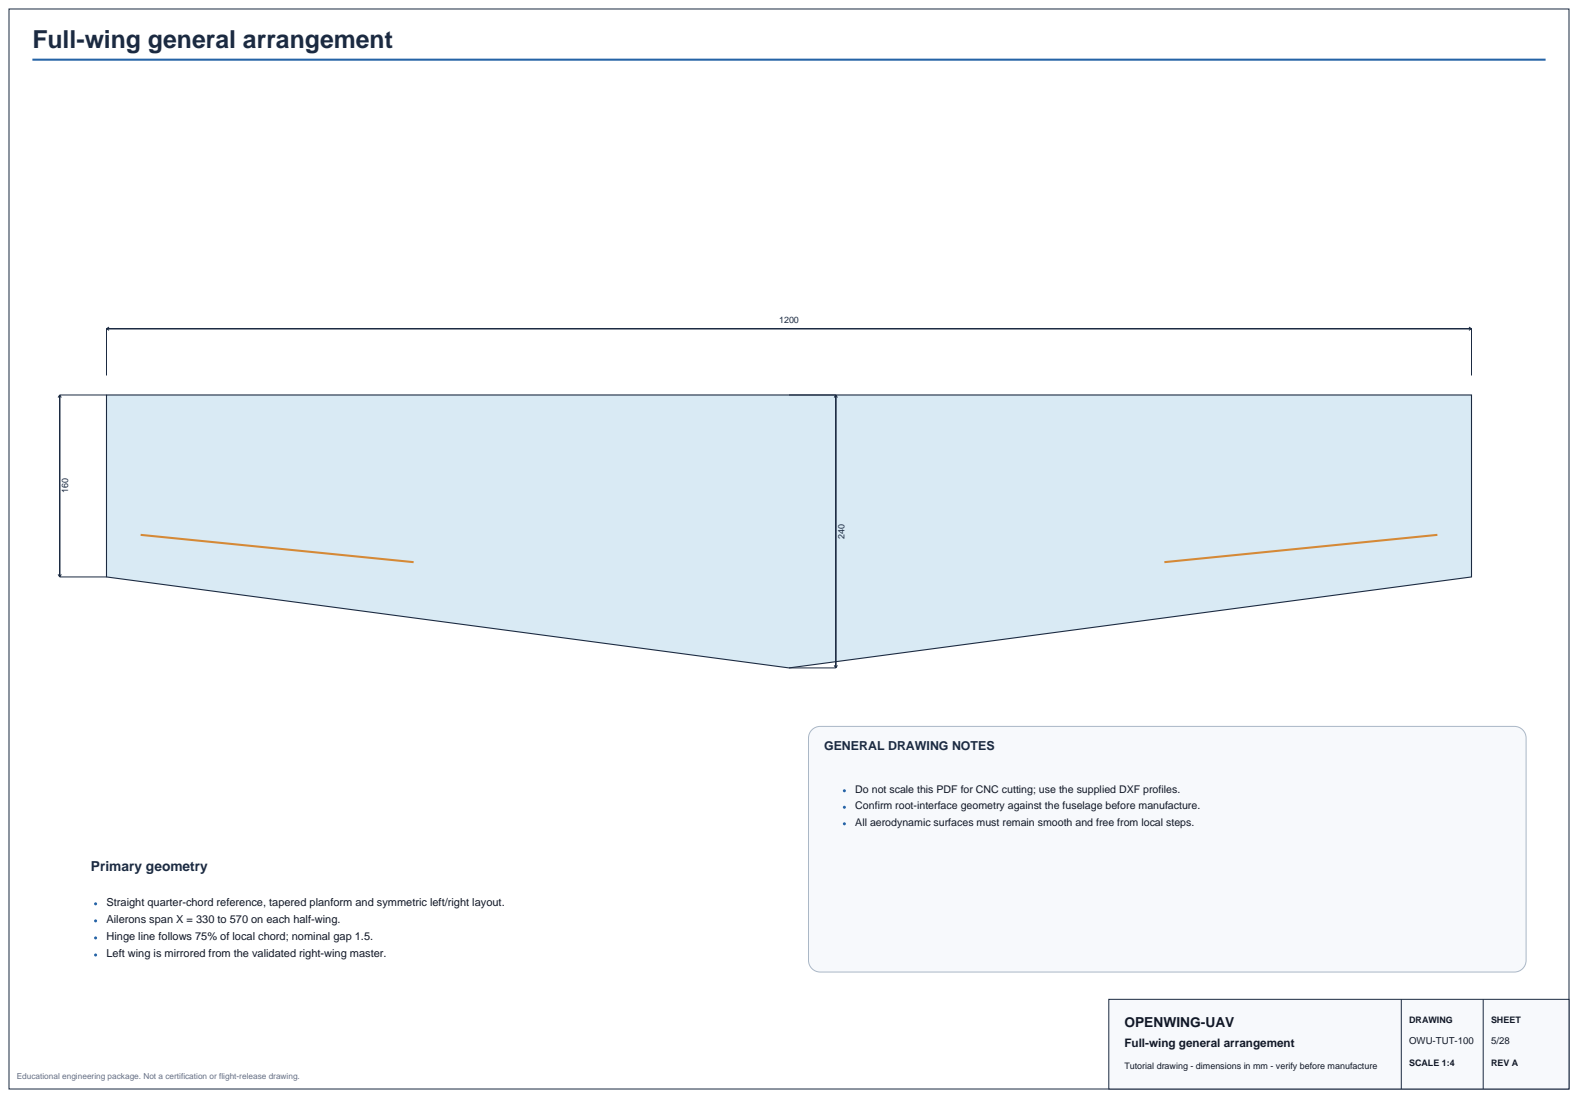
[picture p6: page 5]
Primary geometry; DRAWING; SHEET; OWU-TUT-100; SCALE 1:4; REV A

GENERAL DRAWING NOTES

Do not scale this PDF for CNC cutting; use the supplied DXF profiles.
Confirm root-interface geometry against the fuselage before manufacture.
All aerodynamic surfaces must remain smooth and free from local steps.

Straight quarter-chord reference, tapered planform and symmetric left/right layout.
Ailerons span X = 330 to 570 on each half-wing.
Hinge line follows 75% of local chord; nominal gap 1.5.
Left wing is mirrored from the validated right-wing master.

OPENWING-UAV
Full-wing general arrangement

# Right half-wing structural and station layout

0 | 25 | 75 | 150 | 225 | 300 | 330 | 390 | 450 | 510 | 570 | 600
| | | | | 600
Station X | Chord | Function
0 | 240.0 | Root rib
25 | 236.7 | Root support
75 | 230.0 | Structural
150 | 220.0 | Doubler end
225 | 210.0 | Structural
300 | 200.0 | Midspan
330 | 196.0 | Aileron boundary
390 | 188.0 | Hinge/servo
450 | 180.0 | Servo/hinge
510 | 172.0 | Aileron rib
570 | 164.0 | Aileron boundary
600 | 160.0 | Tip

### COLOUR KEY AND CONSTRUCTION

Main spar - 30% chord

Rear spar - 70% chord

Aileron hinge - 75% chord

Ribs and station planes

Make rib stations and control boundaries configuration-safe.
Preserve a minimum of 1.5 gap at aileron ends and hinge line.
Locate wiring channel through the rib neutral region, clear of spar slots.

## OPENWING-UAV

Right half-wing layout

DRAWING | SHEET
OWU-TUT-110 | 6/28
SCALE 1:2 | REV A

# Dihedral, station rise and washout

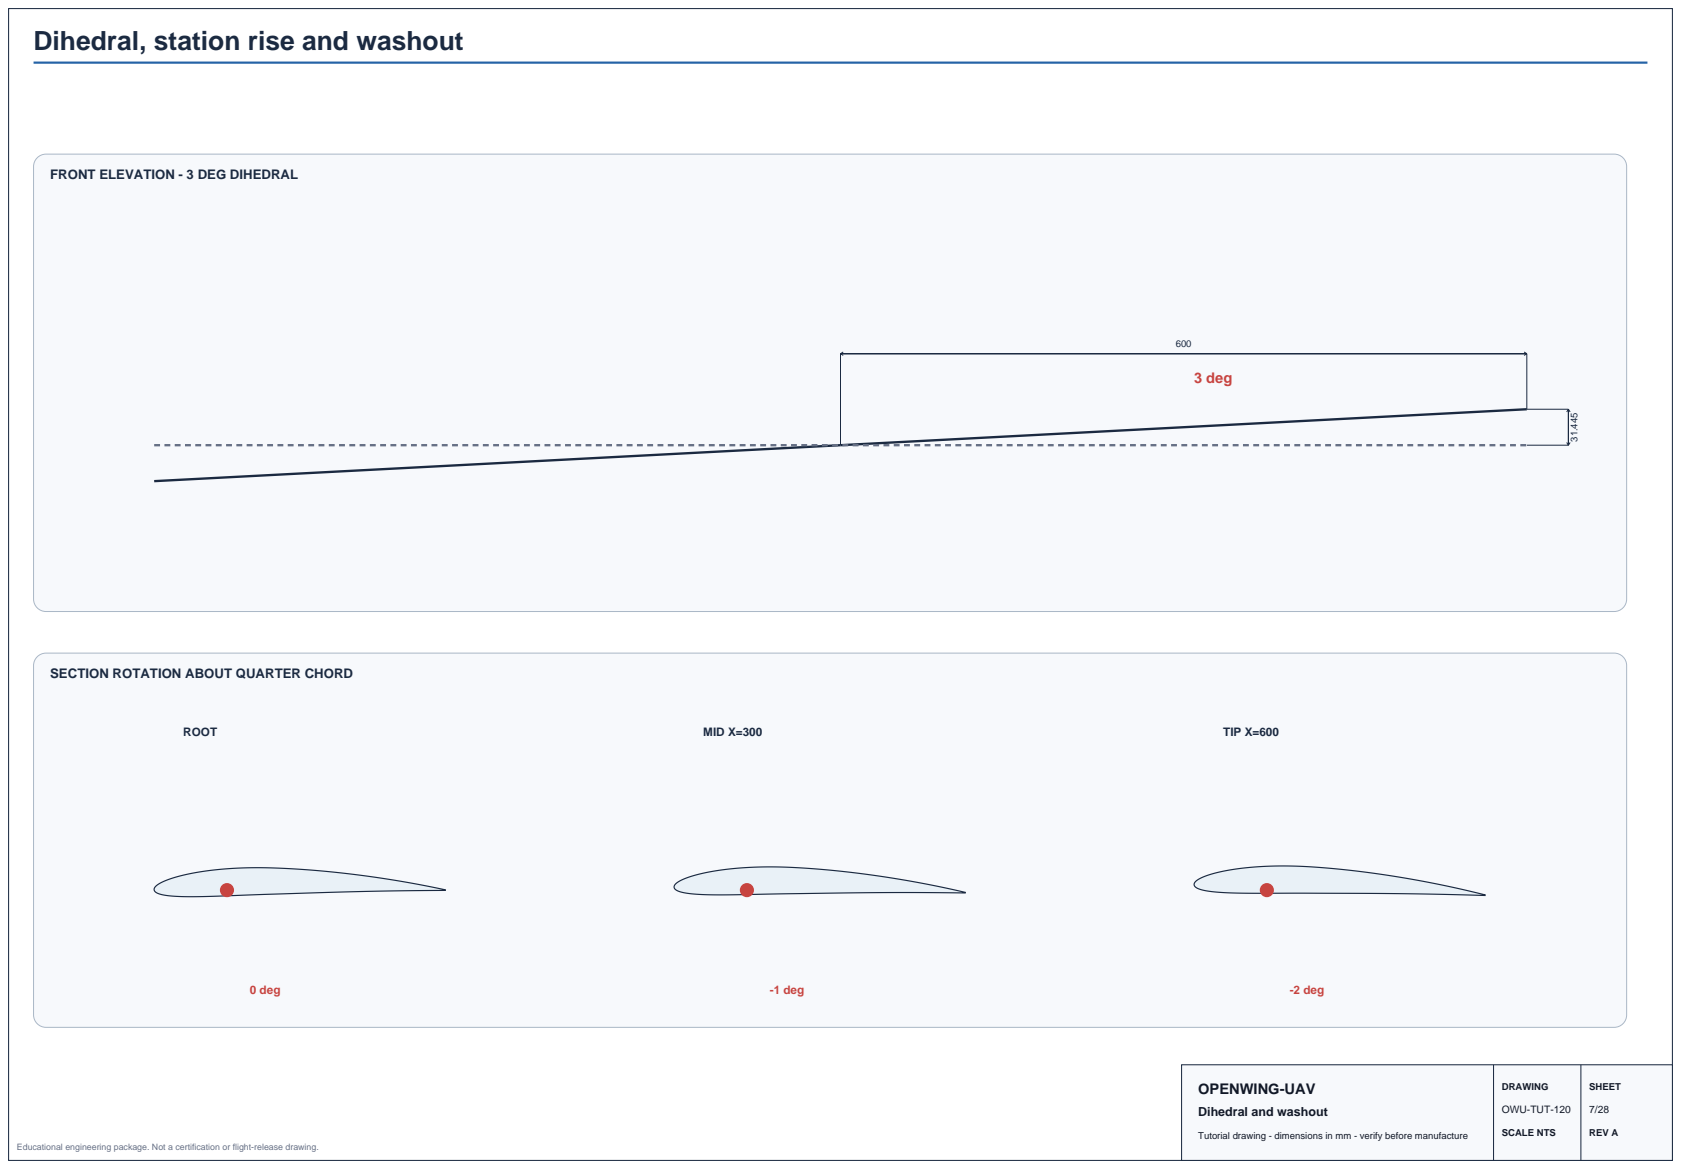
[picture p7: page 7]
3 deg; ROOT; 0 deg; MID X=300; -1 deg; TIP X=600; -2 deg; DRAWING; SHEET; OWU-TUT-120

FRONT ELEVATION - 3 DEG DIHEDRAL

SECTION ROTATION ABOUT QUARTER CHORD

OPENWING-UAV
Dihedral and washout

# NACA 4412 root, midspan and tip sections

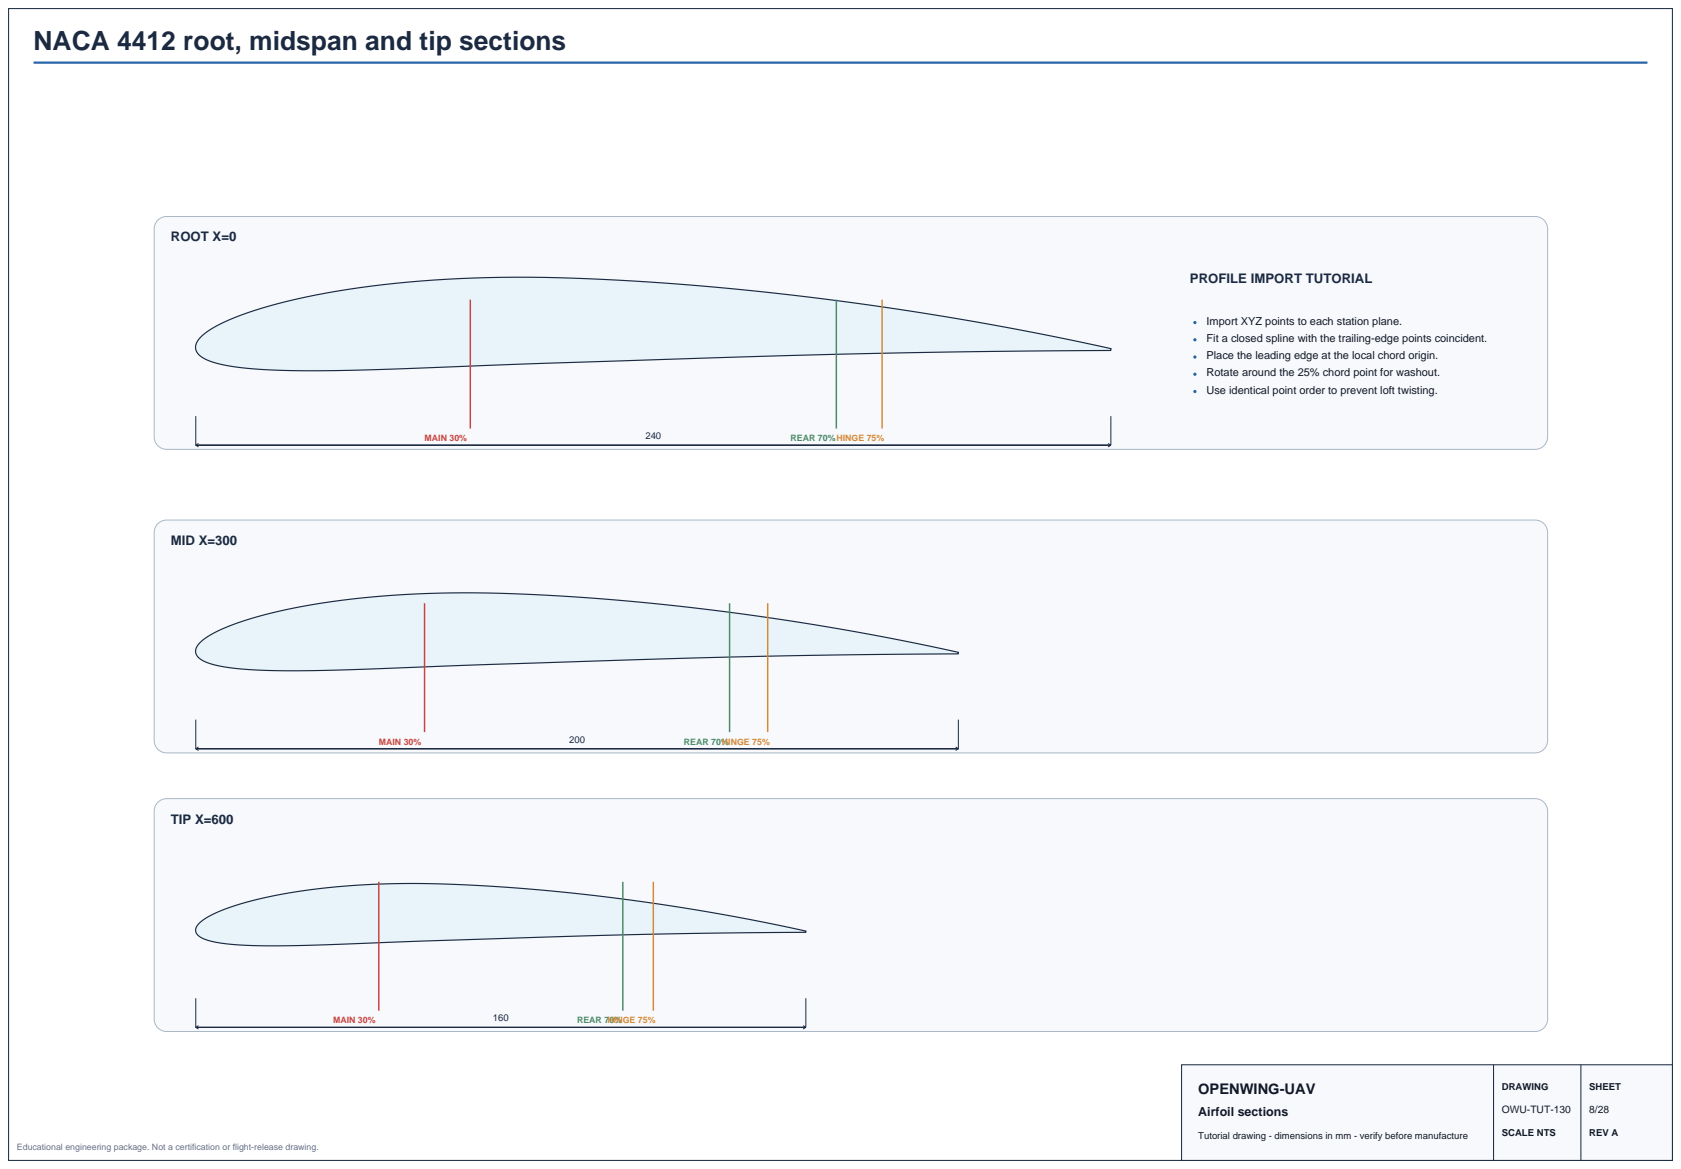
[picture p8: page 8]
ROOT X=0; MAIN 30%; REAR 70%HINGE 75%; MID X=300; TIP X=600; OPENWING-UAV; Airfoil sections; DRAWING; SHEET; OWU-TUT-130

PROFILE IMPORT TUTORIAL

Import XYZ points to each station plane.
Fit a closed spline with the trailing-edge points coincident.
Place the leading edge at the local chord origin.
Rotate around the 25% chord point for washout.
Use identical point order to prevent loft twisting.

# Exploded internal structural architecture

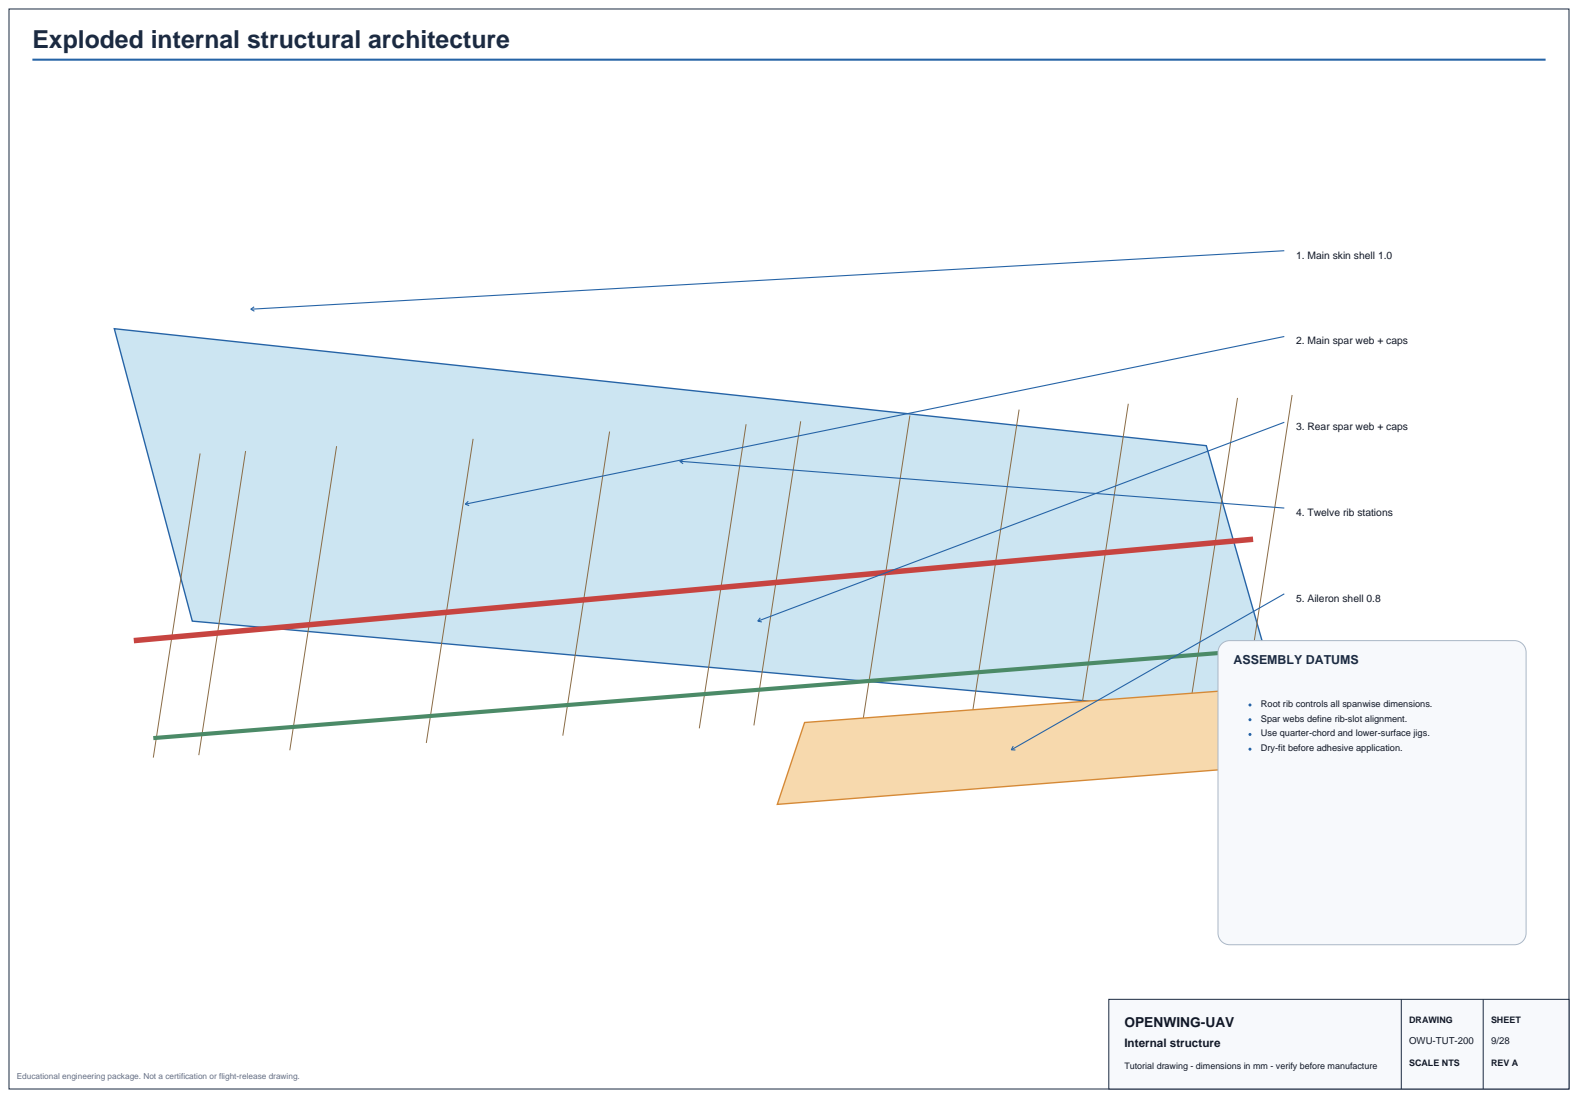
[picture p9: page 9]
5. Aileron shell 0.8; ASSEMBLY DATUMS; OPENWING-UAV; Internal structure; DRAWING; SHEET; OWU-TUT-200

1. Main skin shell 1.0

2. Main spar web + caps

3. Rear spar web + caps

4. Twelve rib stations

Root rib controls all spanwise dimensions.
Spar webs define rib-slot alignment.
Use quarter-chord and lower-surface jigs.
Dry-fit before adhesive application.

# Root rib and root-support interface

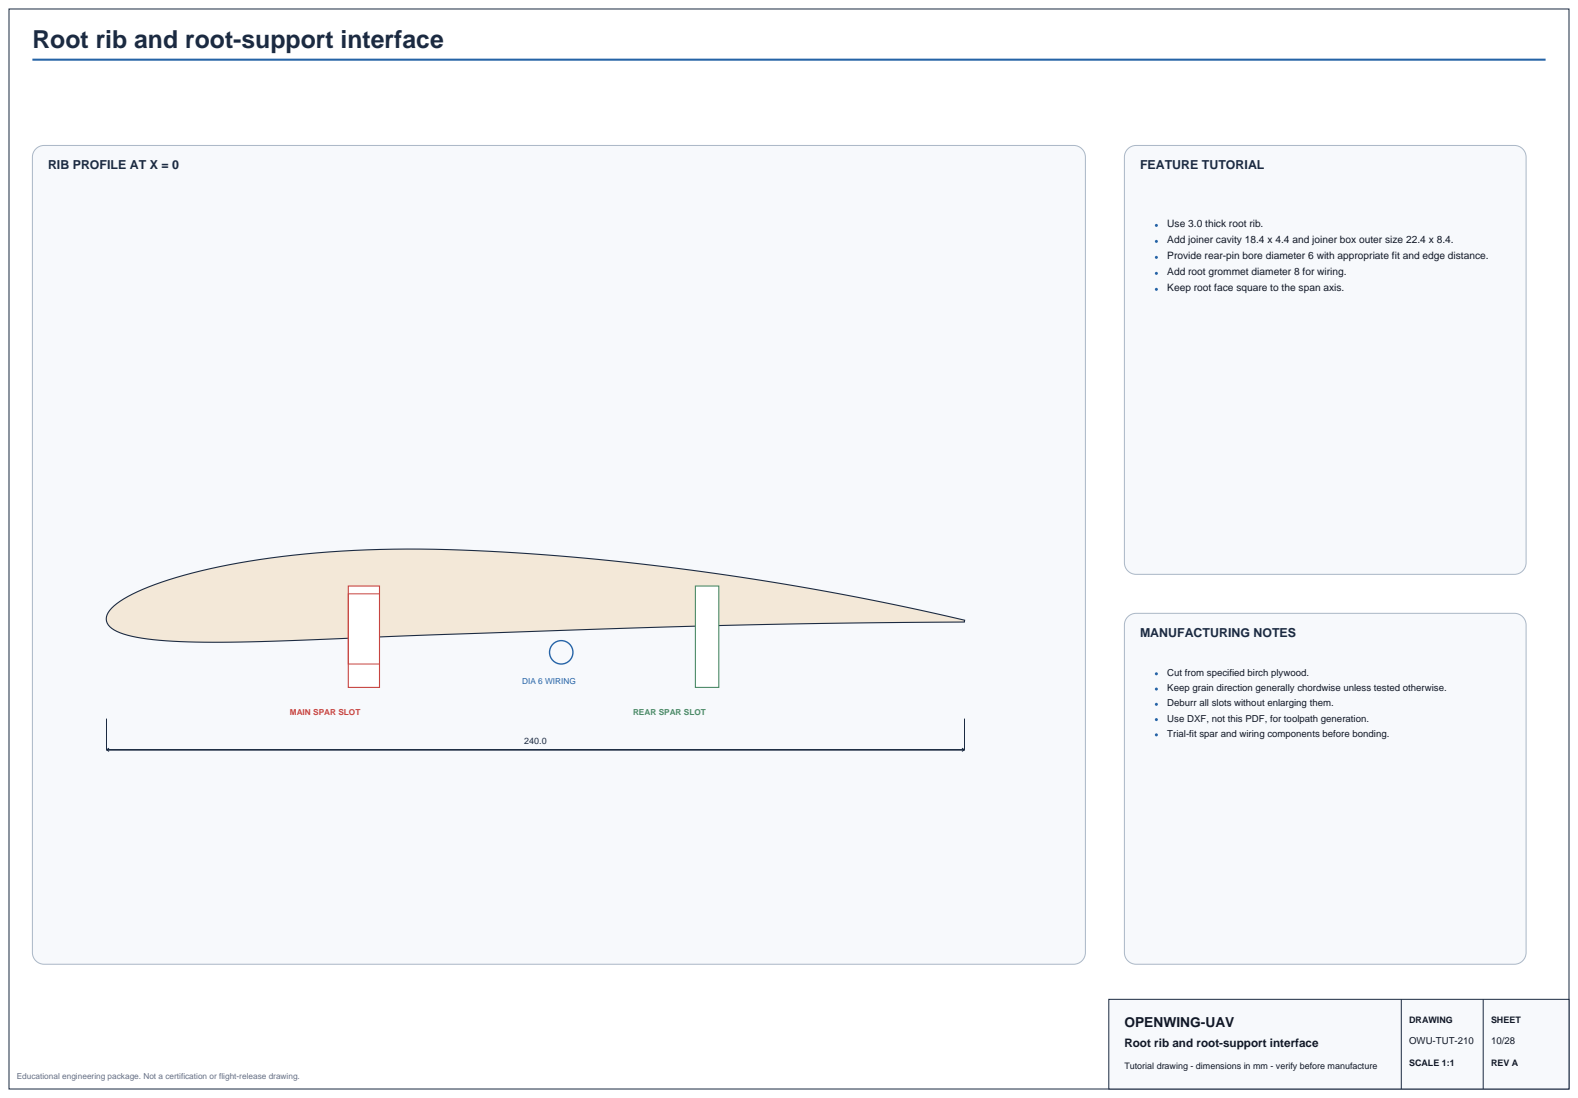
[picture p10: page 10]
MAIN SPAR SLOT; REAR SPAR SLOT; DIA 6 WIRING; FEATURE TUTORIAL; MANUFACTURING NOTES; DRAWING; SHEET; OWU-TUT-210; SCALE 1:1; REV A

RIB PROFILE AT X = 0

Use 3.0 thick root rib.
Add joiner cavity 18.4 x 4.4 and joiner box outer size 22.4 x 8.4.
Provide rear-pin bore diameter 6 with appropriate fit and edge distance.
Add root grommet diameter 8 for wiring.
Keep root face square to the span axis.

Cut from specified birch plywood.
Keep grain direction generally chordwise unless tested otherwise.
Deburr all slots without enlarging them.
Use DXF, not this PDF, for toolpath generation.
Trial-fit spar and wiring components before bonding.

OPENWING-UAV
Root rib and root-support interface

# Typical standard rib

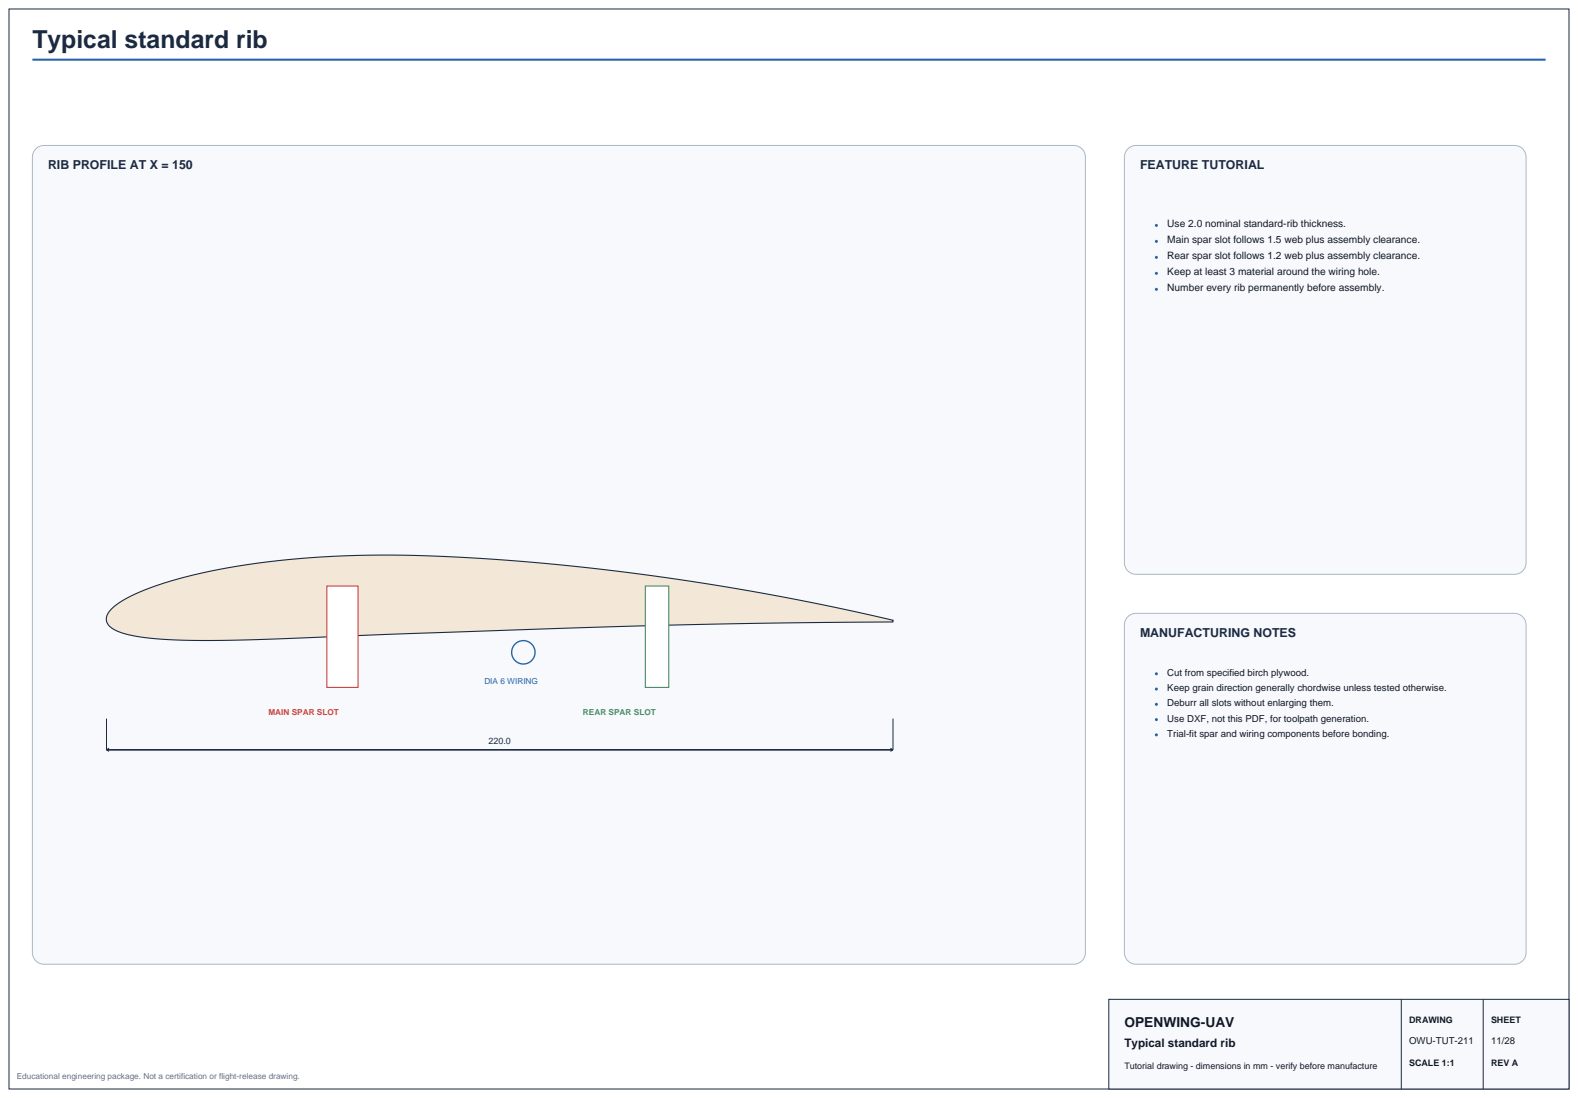
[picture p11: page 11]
MAIN SPAR SLOT; REAR SPAR SLOT; DIA 6 WIRING; FEATURE TUTORIAL; MANUFACTURING NOTES; DRAWING; SHEET; OWU-TUT-211; SCALE 1:1; REV A

RIB PROFILE AT X = 150

Use 2.0 nominal standard-rib thickness.
Main spar slot follows 1.5 web plus assembly clearance.
Rear spar slot follows 1.2 web plus assembly clearance.
Keep at least 3 material around the wiring hole.
Number every rib permanently before assembly.

Cut from specified birch plywood.
Keep grain direction generally chordwise unless tested otherwise.
Deburr all slots without enlarging them.
Use DXF, not this PDF, for toolpath generation.
Trial-fit spar and wiring components before bonding.

OPENWING-UAV
Typical standard rib

# Servo-bay and control-system rib

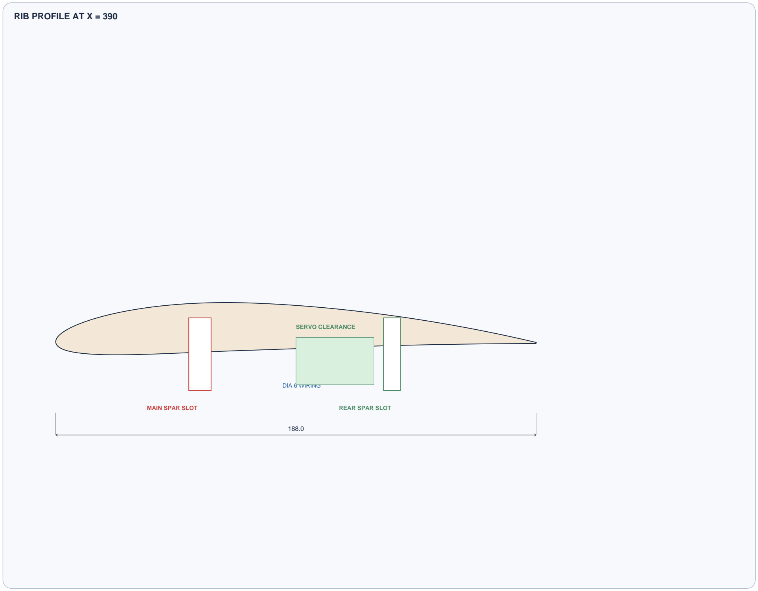
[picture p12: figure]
RIB PROFILE AT X = 390; MAIN SPAR SLOT; REAR SPAR SLOT; DIA 6 WIRING; SERVO CLEARANCE

### FEATURE TUTORIAL

Use the X=390 and X=450 ribs to bound the servo bay.
Preserve clearance for a 24 x 13 x 25 generic micro-servo envelope. Provide tray attachment lands without weakening spar slots.
Align pushrod path with the aileron horn and avoid side loading. Check full +20 / -15 deg aileron travel in assembly.

### MANUFACTURING NOTES

Cut from specified birch plywood.
Keep grain direction generally chordwise unless tested otherwise. Deburr all slots without enlarging them.
Use DXF, not this PDF, for toolpath generation.
Trial-fit spar and wiring components before bonding.

## OPENWING-UAV

Servo-bay and control-system rib

DRAWING | SHEET
OWU-TUT-212 | 12/28
SCALE 1:1 | REV A

# Main and rear spar system

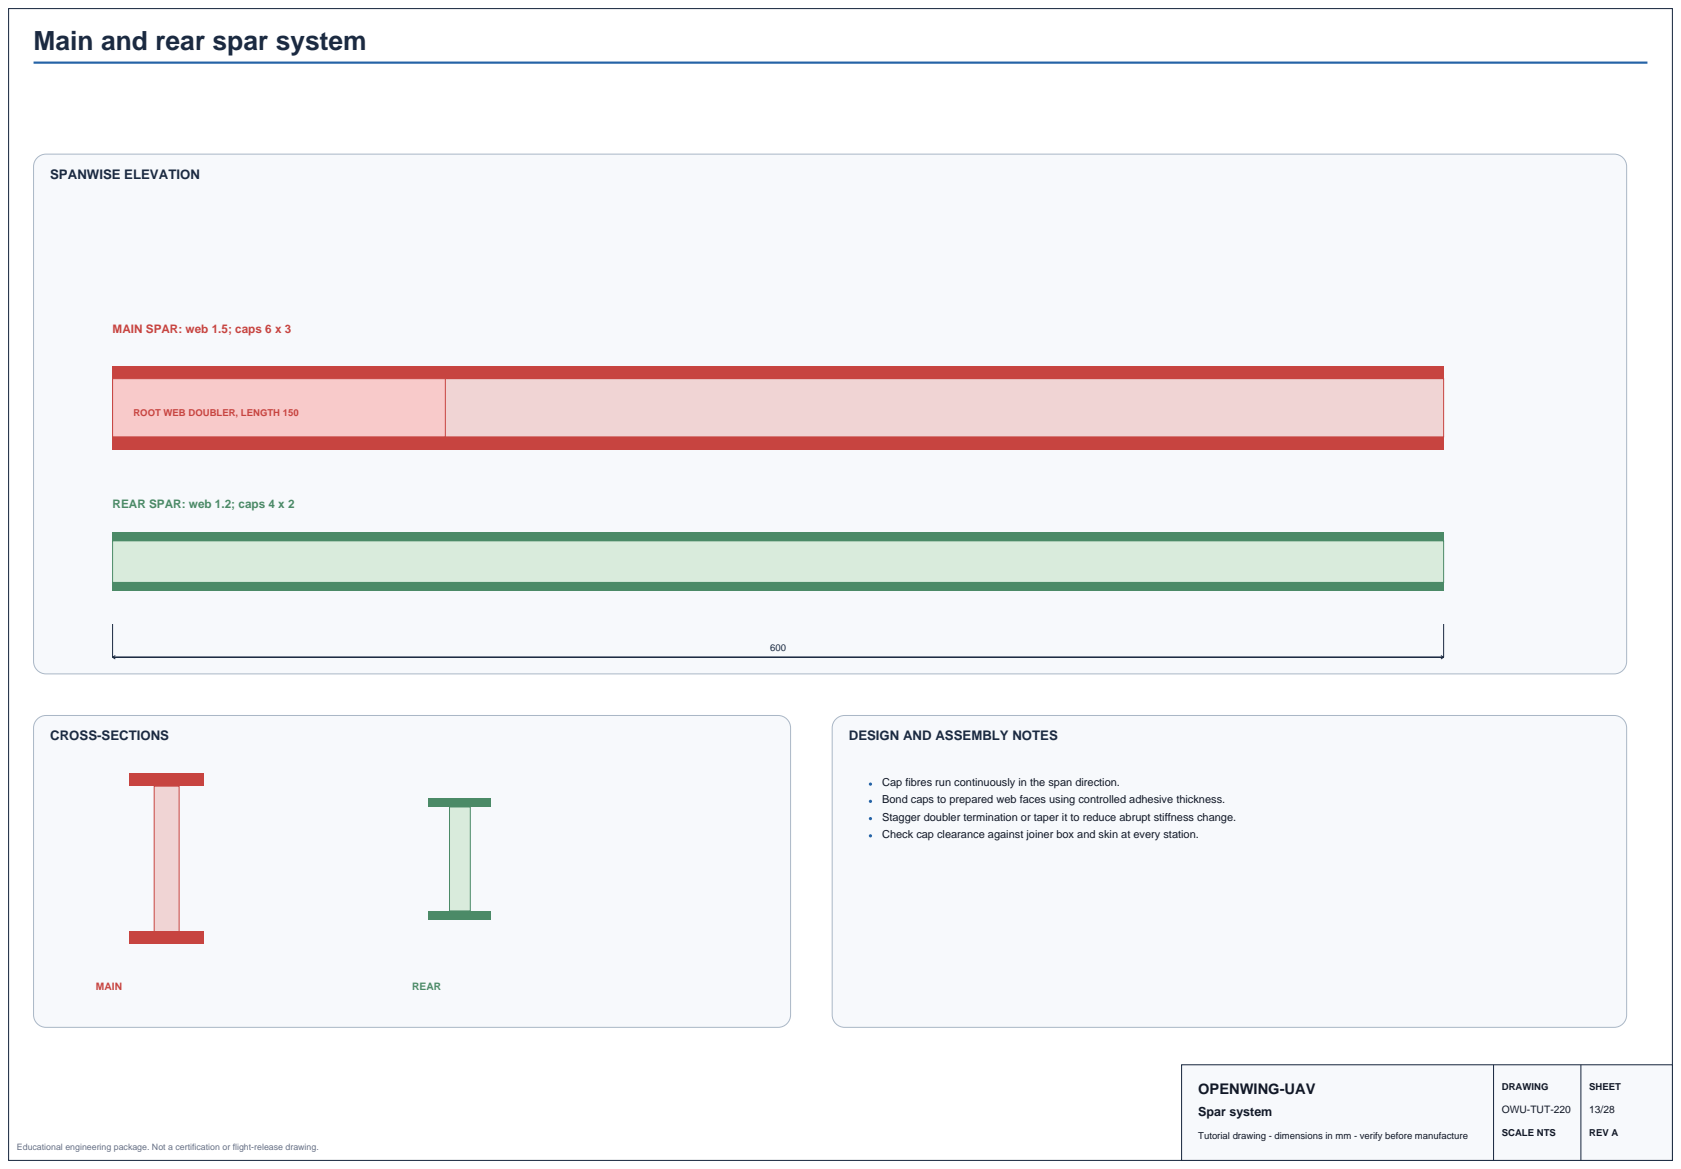
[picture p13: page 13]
SPANWISE ELEVATION; CROSS-SECTIONS; MAIN; REAR; OPENWING-UAV; Spar system; DRAWING; SHEET; OWU-TUT-220

MAIN SPAR: web 1.5; caps 6 x 3

ROOT WEB DOUBLER, LENGTH 150

REAR SPAR: web 1.2; caps 4 x 2

DESIGN AND ASSEMBLY NOTES

Cap fibres run continuously in the span direction.
Bond caps to prepared web faces using controlled adhesive thickness.
Stagger doubler termination or taper it to reduce abrupt stiffness change.
Check cap clearance against joiner box and skin at every station.

# V-joiner, joiner box and removable root interface

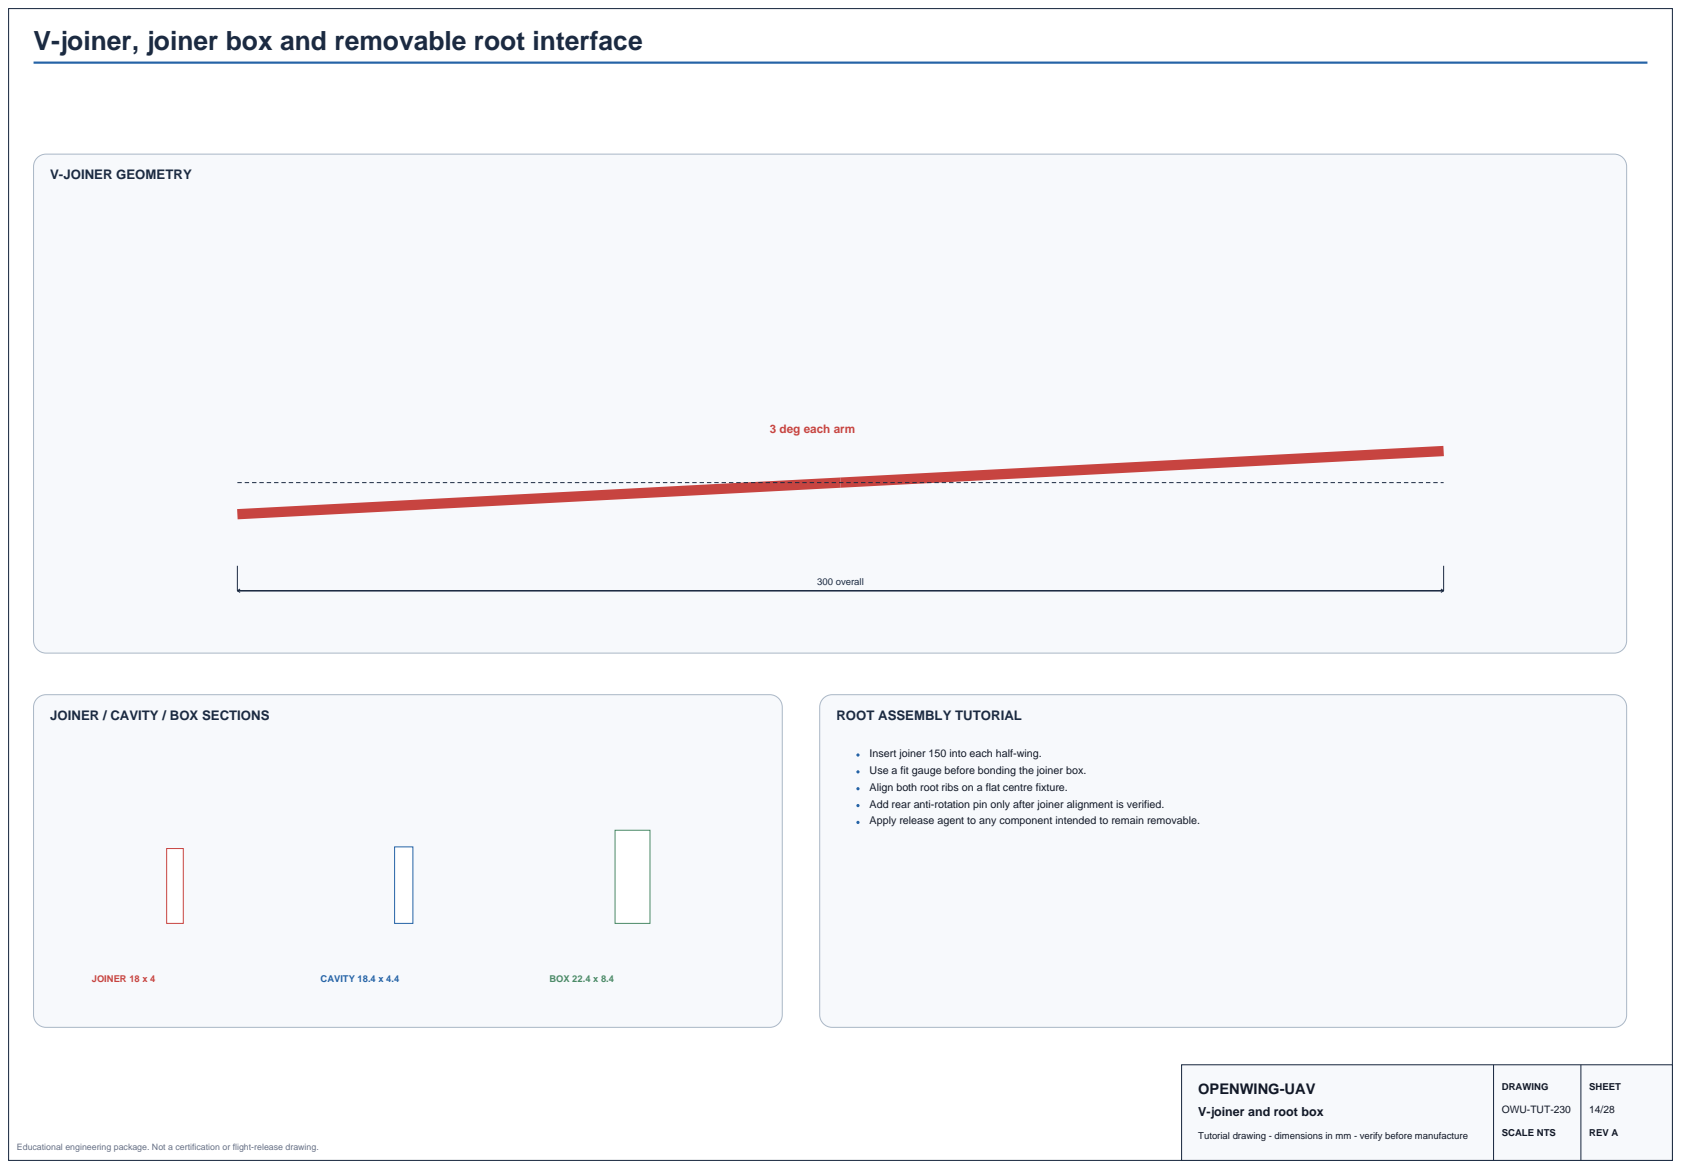
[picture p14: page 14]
V-JOINER GEOMETRY; 300 overall; JOINER 18 x 4; CAVITY 18.4 x 4.4; BOX 22.4 x 8.4; DRAWING; SHEET; OWU-TUT-230

3 deg each arm

JOINER / CAVITY / BOX SECTIONS

ROOT ASSEMBLY TUTORIAL

Insert joiner 150 into each half-wing.
Use a fit gauge before bonding the joiner box.
Align both root ribs on a flat centre fixture.
Add rear anti-rotation pin only after joiner alignment is verified.
Apply release agent to any component intended to remain removable.

OPENWING-UAV
V-joiner and root box

# Rear anti-rotation pin and root load path

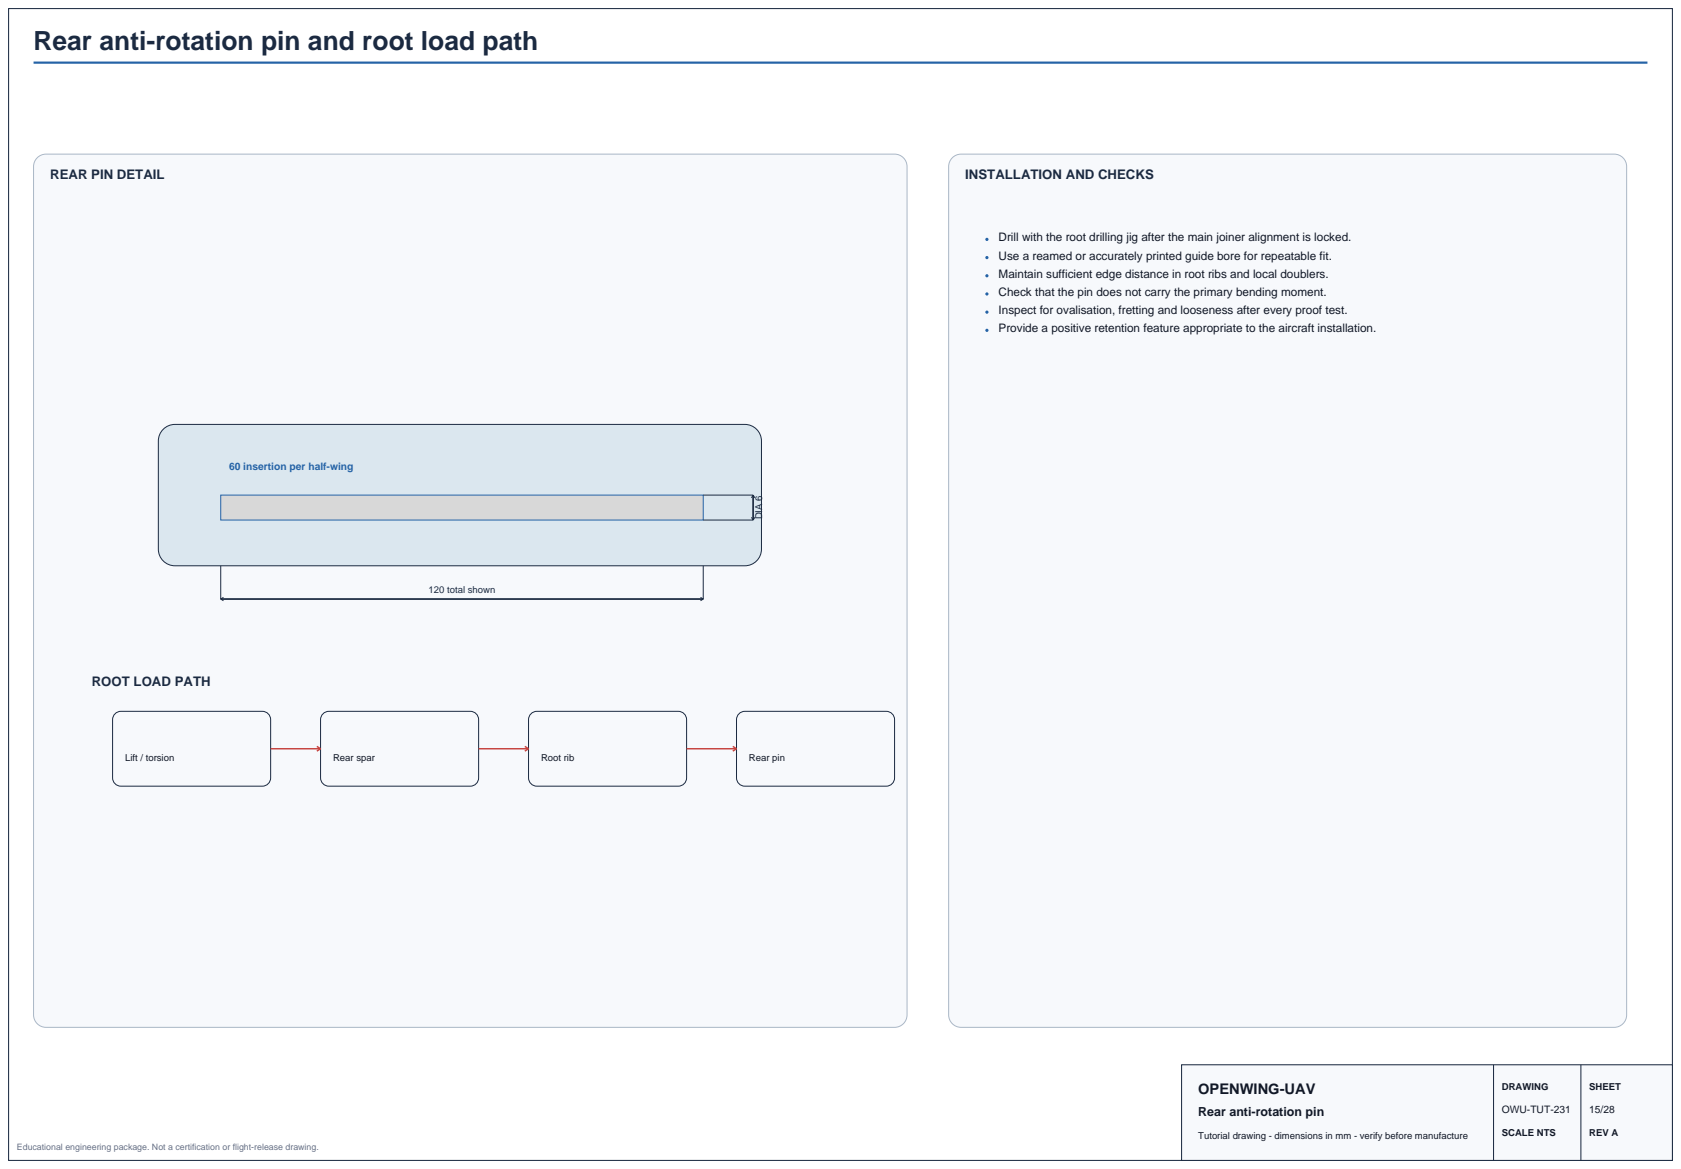
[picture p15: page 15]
120 total shown; DIA 6; Lift / torsion; Rear spar; Root rib; Rear pin; DRAWING; SHEET; OWU-TUT-231

REAR PIN DETAIL

INSTALLATION AND CHECKS

Drill with the root drilling jig after the main joiner alignment is locked.
Use a reamed or accurately printed guide bore for repeatable fit.
Maintain sufficient edge distance in root ribs and local doublers.
Check that the pin does not carry the primary bending moment.
Inspect for ovalisation, fretting and looseness after every proof test.
Provide a positive retention feature appropriate to the aircraft installation.

60 insertion per half-wing

ROOT LOAD PATH

OPENWING-UAV
Rear anti-rotation pin

# Aileron geometry, gaps and motion envelope

75% local-chord hinge line

CONTROL-SURFACE NOTES

Nominal hinge-line and end gaps: 1.5.
Aileron shell nominal thickness: 0.8.
Hinge stations: X = 360, 450 and 540.
Check motion under servo stall and wing deflection.

# Aileron hinge fitting and pin

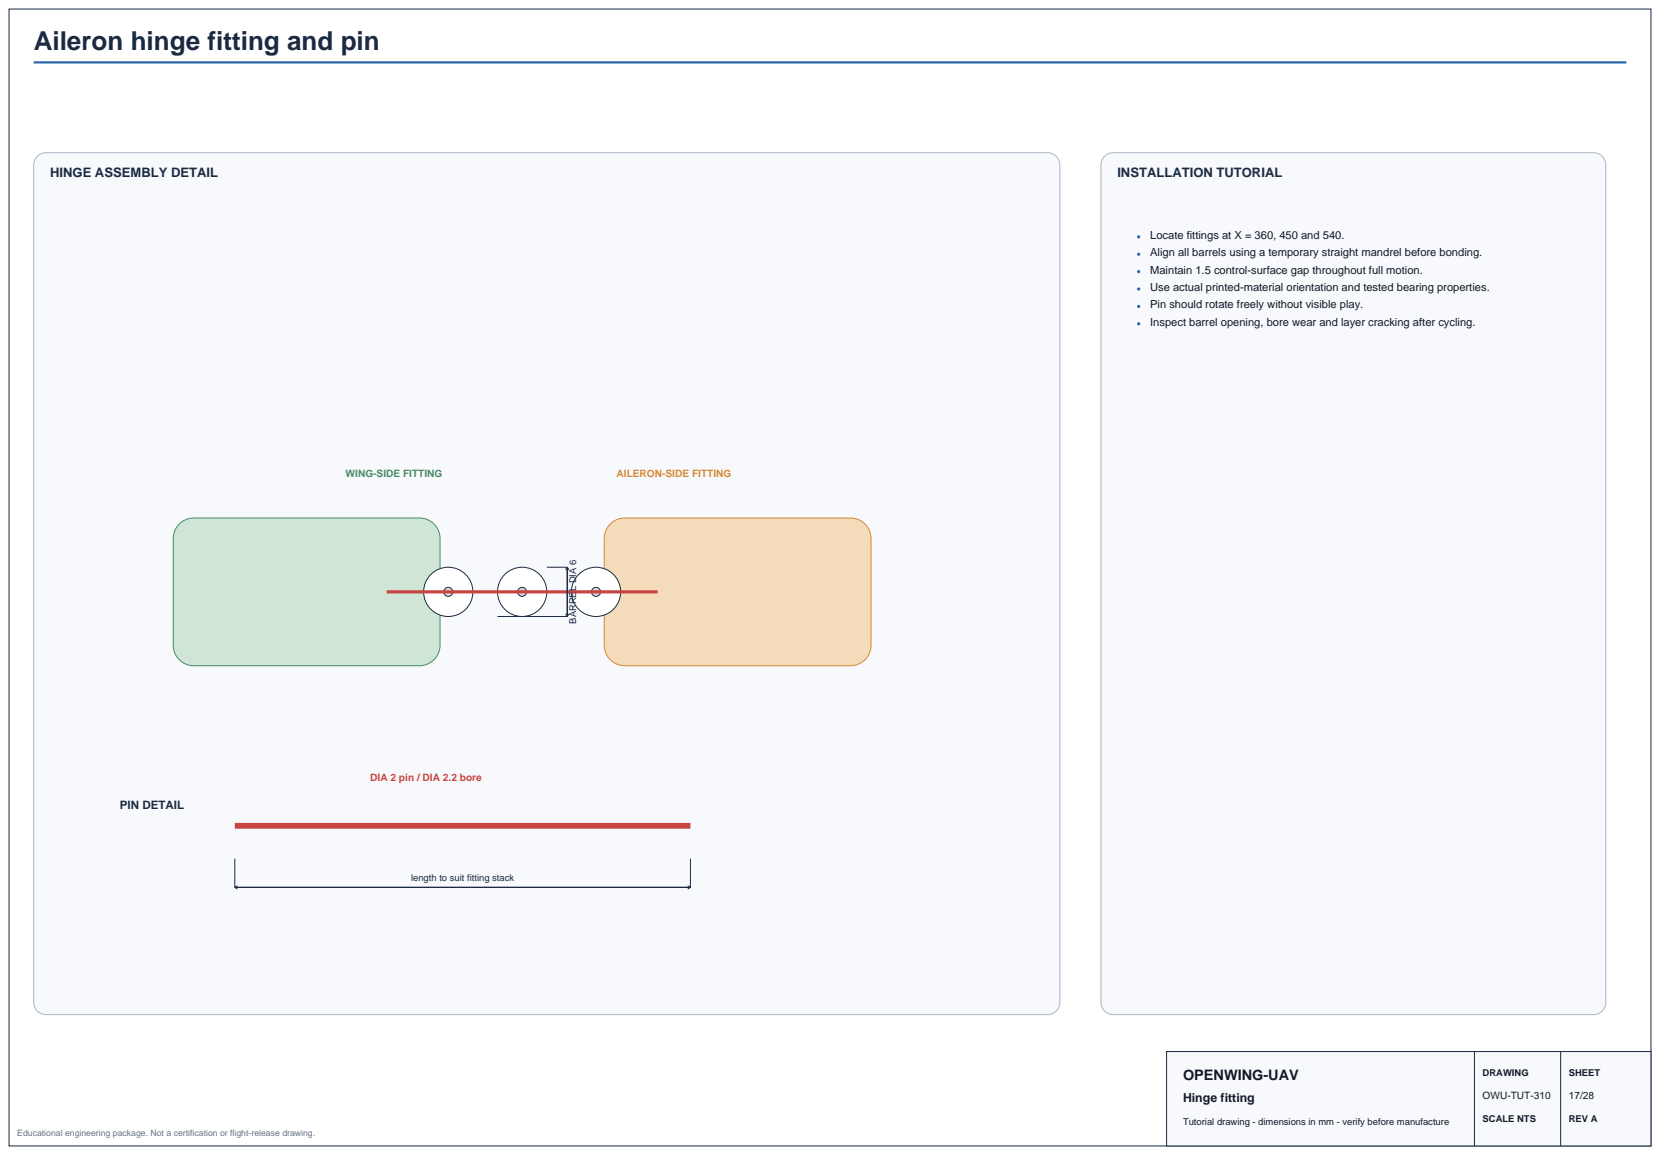
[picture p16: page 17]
BARREL DIA 6; WING-SIDE FITTING; AILERON-SIDE FITTING; PIN DETAIL; INSTALLATION TUTORIAL; OPENWING-UAV; Hinge fitting; DRAWING; SHEET; OWU-TUT-310

HINGE ASSEMBLY DETAIL

Locate fittings at X = 360, 450 and 540.
Align all barrels using a temporary straight mandrel before bonding.
Maintain 1.5 control-surface gap throughout full motion.
Use actual printed-material orientation and tested bearing properties.
Pin should rotate freely without visible play.
Inspect barrel opening, bore wear and layer cracking after cycling.

DIA 2 pin / DIA 2.2 bore

length to suit fitting stack

# Servo bay, tray and linkage geometry

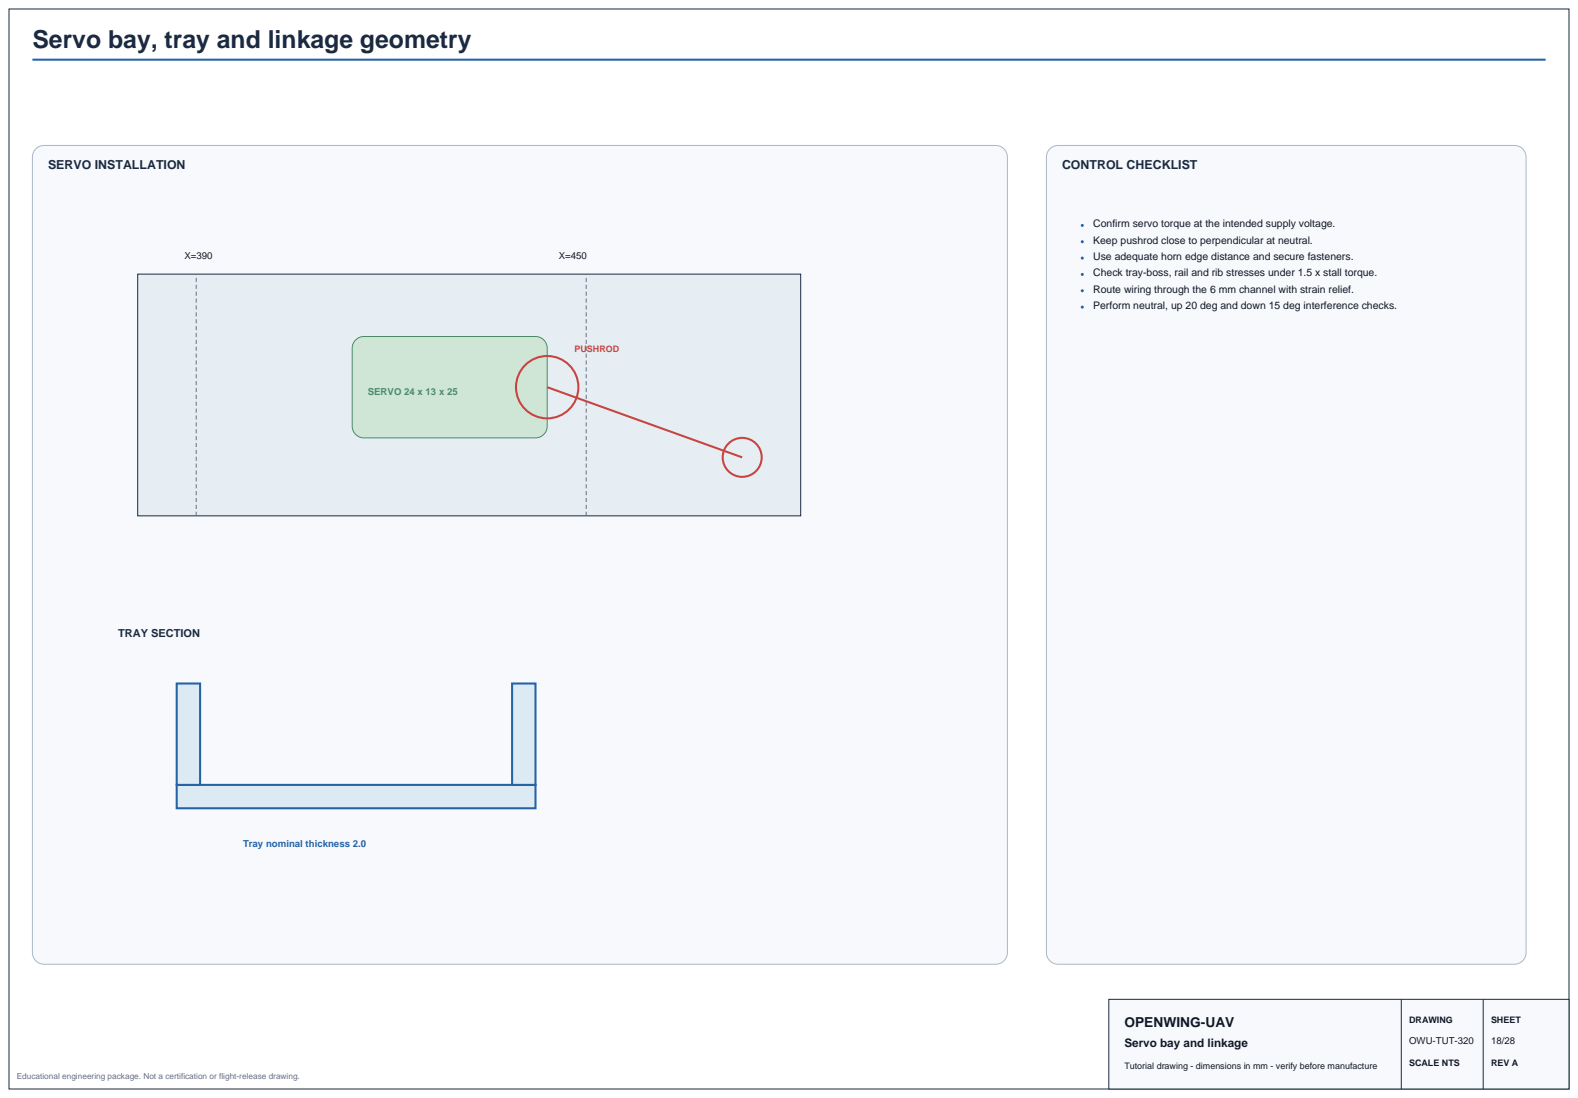
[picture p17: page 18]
SERVO INSTALLATION; SERVO 24 x 13 x 25; PUSHROD; TRAY SECTION; CONTROL CHECKLIST; DRAWING; SHEET; OWU-TUT-320

Confirm servo torque at the intended supply voltage.
Keep pushrod close to perpendicular at neutral.
Use adequate horn edge distance and secure fasteners.
Check tray-boss, rail and rib stresses under 1.5 x stall torque.
Route wiring through the 6 mm channel with strain relief.
Perform neutral, up 20 deg and down 15 deg interference checks.

Tray nominal thickness 2.0

OPENWING-UAV
Servo bay and linkage

# Removable 50 mm wingtip cap

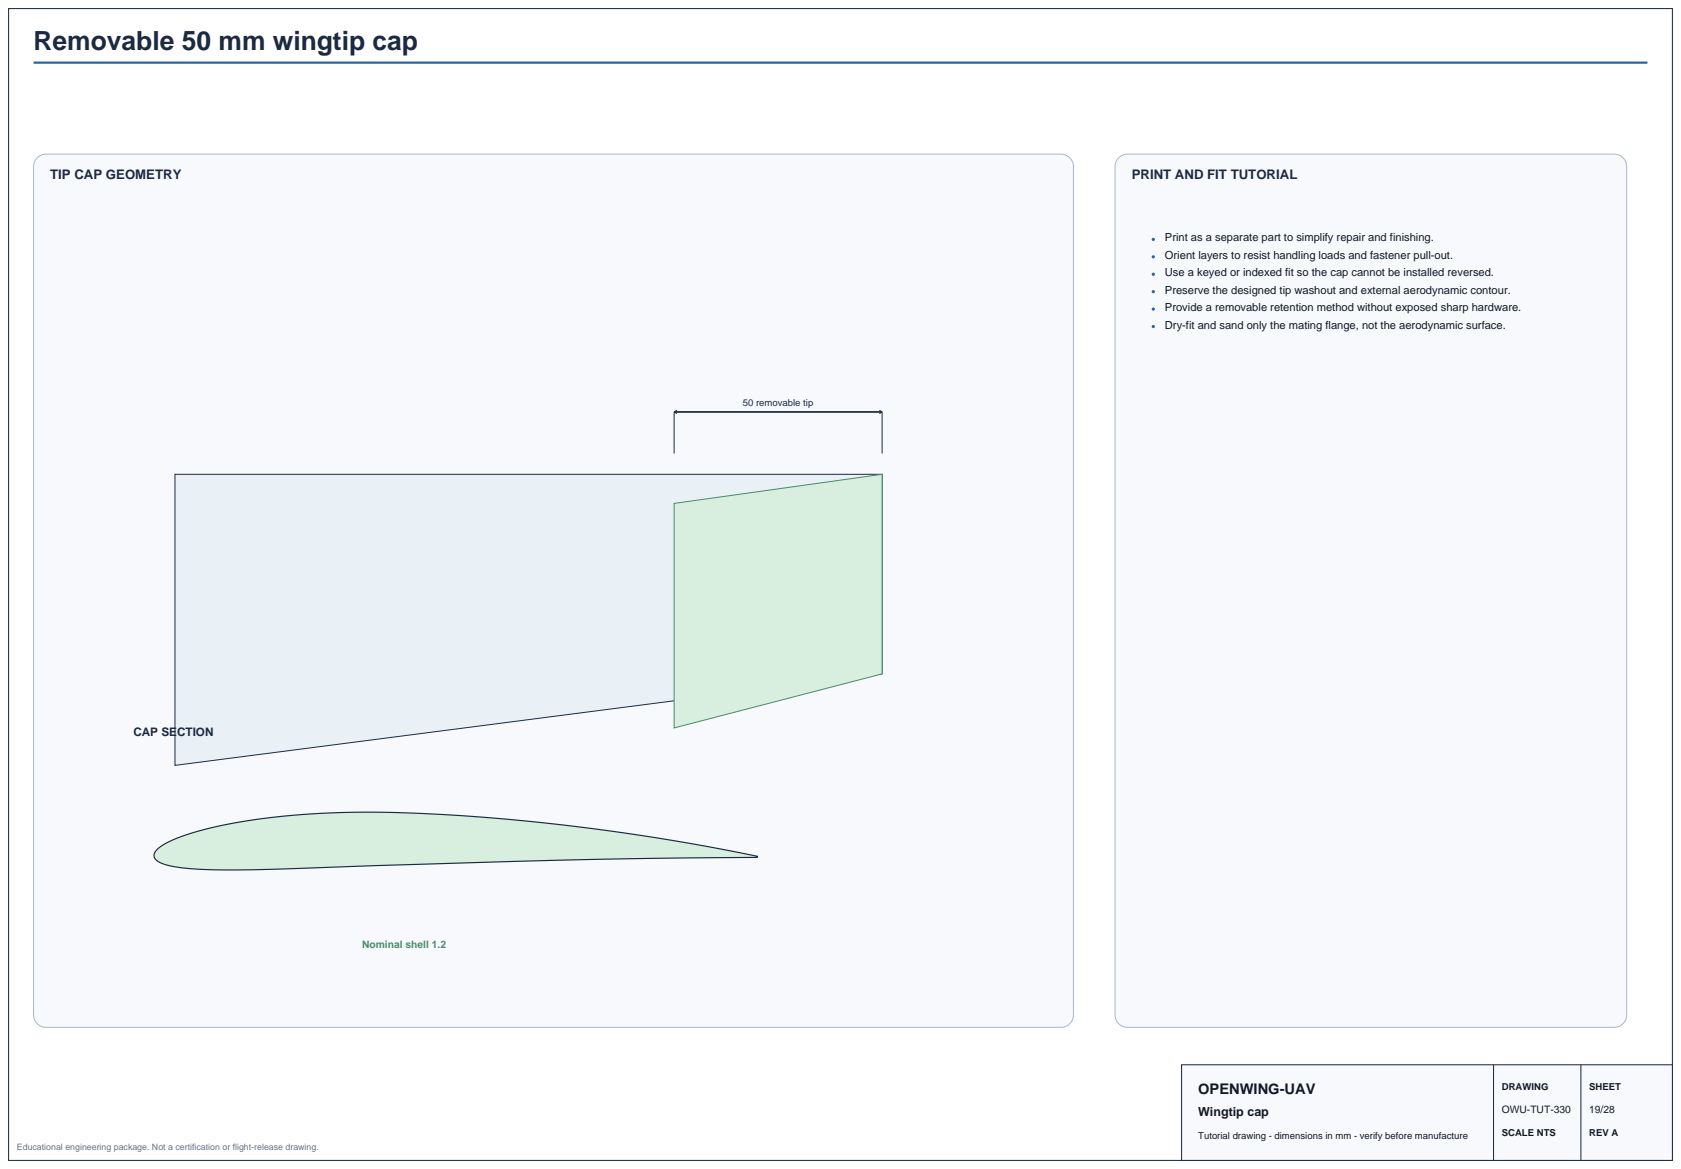
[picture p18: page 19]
50 removable tip; CAP SECTION; Nominal shell 1.2; OPENWING-UAV; Wingtip cap; DRAWING; SHEET; OWU-TUT-330

TIP CAP GEOMETRY

PRINT AND FIT TUTORIAL

Print as a separate part to simplify repair and finishing.
Orient layers to resist handling loads and fastener pull-out.
Use a keyed or indexed fit so the cap cannot be installed reversed.
Preserve the designed tip washout and external aerodynamic contour.
Provide a removable retention method without exposed sharp hardware.
Dry-fit and sand only the mating flange, not the aerodynamic surface.

# Wing skin, aileron shell and adhesive bonding sequence

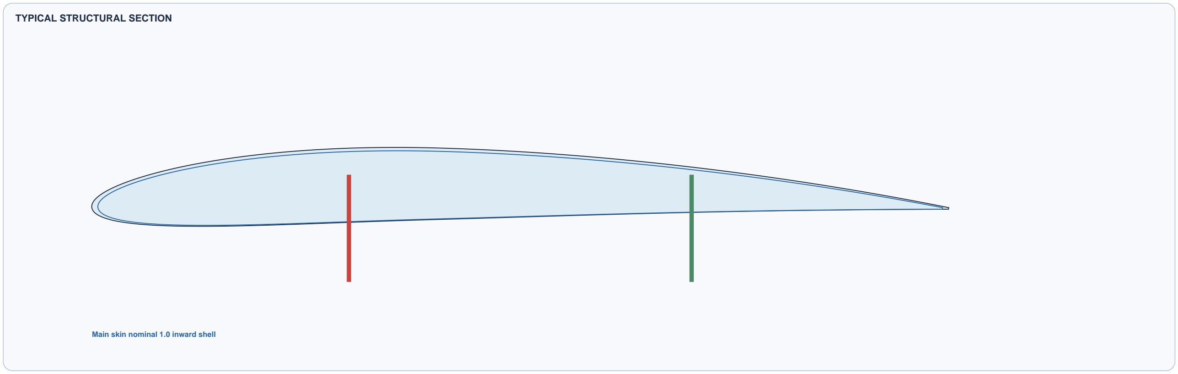
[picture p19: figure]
TYPICAL STRUCTURAL SECTION; Main skin nominal 1.0 inward shell

### BONDING SEQUENCE

1. Abrade and clean all bond surfaces.
2. Bond caps to spar webs and cure in straight jigs.
3. Bond ribs to spars using alignment jigs.
4. Install wiring and servo tray before closing skin.
5. Bond lower skin, inspect, then bond upper skin.
6. Keep control gaps and removable root interfaces free of adhesive.

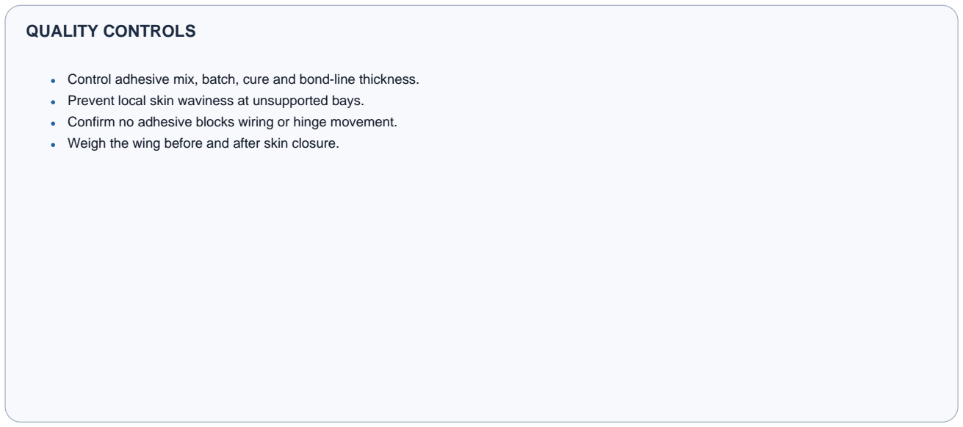
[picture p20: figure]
QUALITY CONTROLS

Control adhesive mix, batch, cure and bond-line thickness. Prevent local skin waviness at unsupported bays. Confirm no adhesive blocks wiring or hinge movement. Weigh the wing before and after skin closure.

## OPENWING-UAV

Skin and bonding

DRAWING | SHEET
OWU-TUT-400 | 20/28

# Assembly sequence A - root, spars and ribs

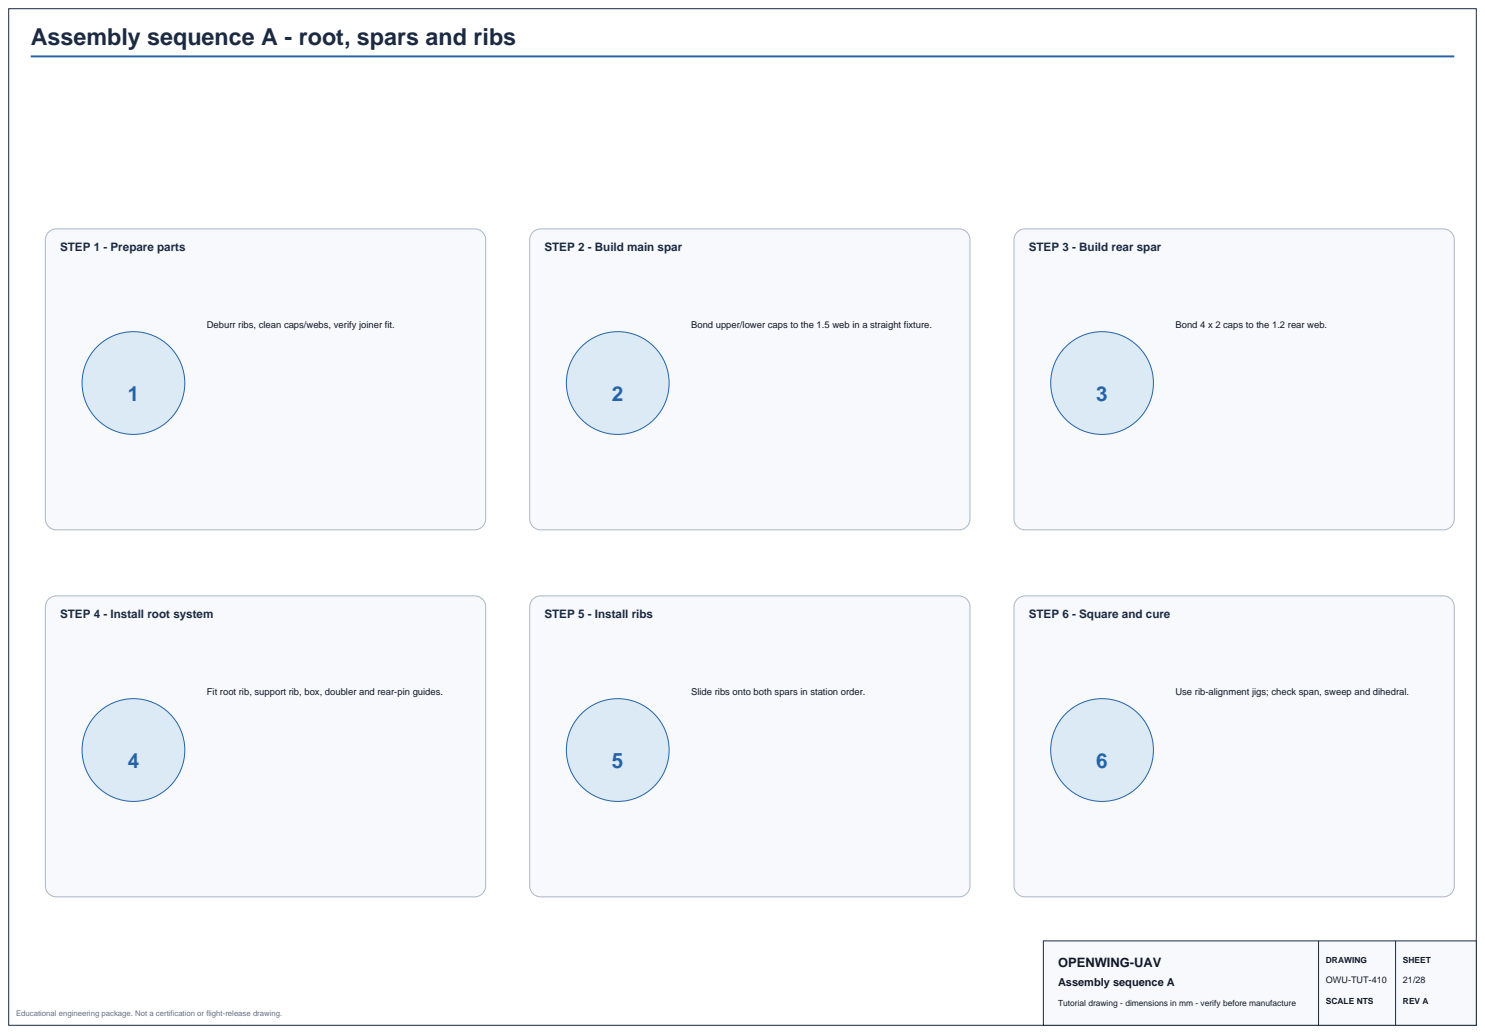
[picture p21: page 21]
OPENWING-UAV; Assembly sequence A; DRAWING; SHEET; OWU-TUT-410

STEP 1 - Prepare parts

STEP 2 - Build main spar

STEP 3 - Build rear spar

Deburr ribs, clean caps/webs, verify joiner fit.

Bond upper/lower caps to the 1.5 web in a straight fixture.

Bond 4 x 2 caps to the 1.2 rear web.

STEP 4 - Install root system

STEP 5 - Install ribs

STEP 6 - Square and cure

Fit root rib, support rib, box, doubler and rear-pin guides.

Slide ribs onto both spars in station order.

Use rib-alignment jigs; check span, sweep and dihedral.

# Assembly sequence B - systems, skins and controls

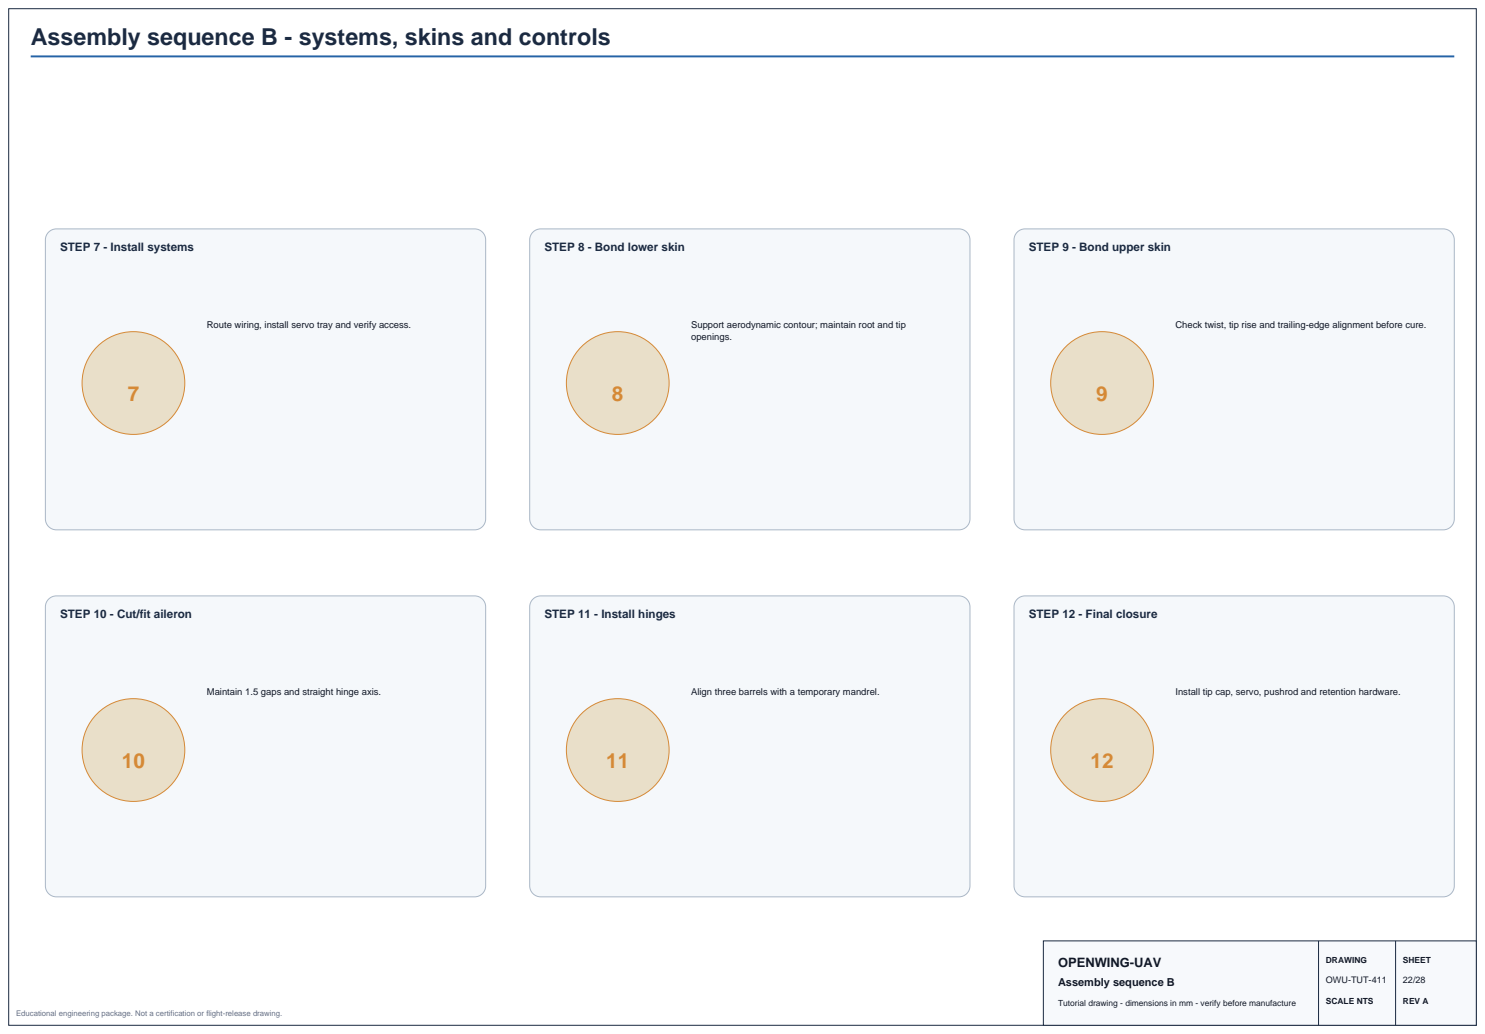
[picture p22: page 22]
OPENWING-UAV; Assembly sequence B; DRAWING; SHEET; OWU-TUT-411

STEP 7 - Install systems

STEP 8 - Bond lower skin

STEP 9 - Bond upper skin

Route wiring, install servo tray and verify access.

Support aerodynamic contour; maintain root and tip
openings.

Check twist, tip rise and trailing-edge alignment before cure.

STEP 10 - Cut/fit aileron

STEP 11 - Install hinges

STEP 12 - Final closure

Maintain 1.5 gaps and straight hinge axis.

Align three barrels with a temporary mandrel.

Install tip cap, servo, pushrod and retention hardware.

# SolidWorks 2023 modelling workflow

01

Master equations

Create span, chords, dihedral, washout, spar fractions and station dimensions.

02

Profile planes

Create X=0, 300 and 600 planes; add quarter-chord points and Z rises.

03

Airfoil sketches

Import NACA 4412 XYZ data; scale to 240, 200 and 160 chords.

04

Guide curves

Create leading-edge and trailing-edge guides; verify pierce relations.

05

Wing envelope

Use Boundary Surface or Loft; knit and close to create a reference solid.

06

Skin shells

Offset inward 1.0 for wing and 0.8 for aileron; split at control boundaries.

07

Spars and ribs

Create equation-driven spar surfaces/solids and rib intersections.

08

Root and controls

Add joiner box, rear pin, servo bay, hinges, wiring and tip cap.

09

Assemblies

Create right wing, mirrored left wing and full-wing assembly.

10

Drawings/exports

Create A3 drawings; export STEP, STL/3MF and DXF by released revision.

## OPENWING-UAV

SolidWorks modelling workflow

DRAWING | SHEET
OWU-TUT-500 | 23/28

# Static structural simulation setup

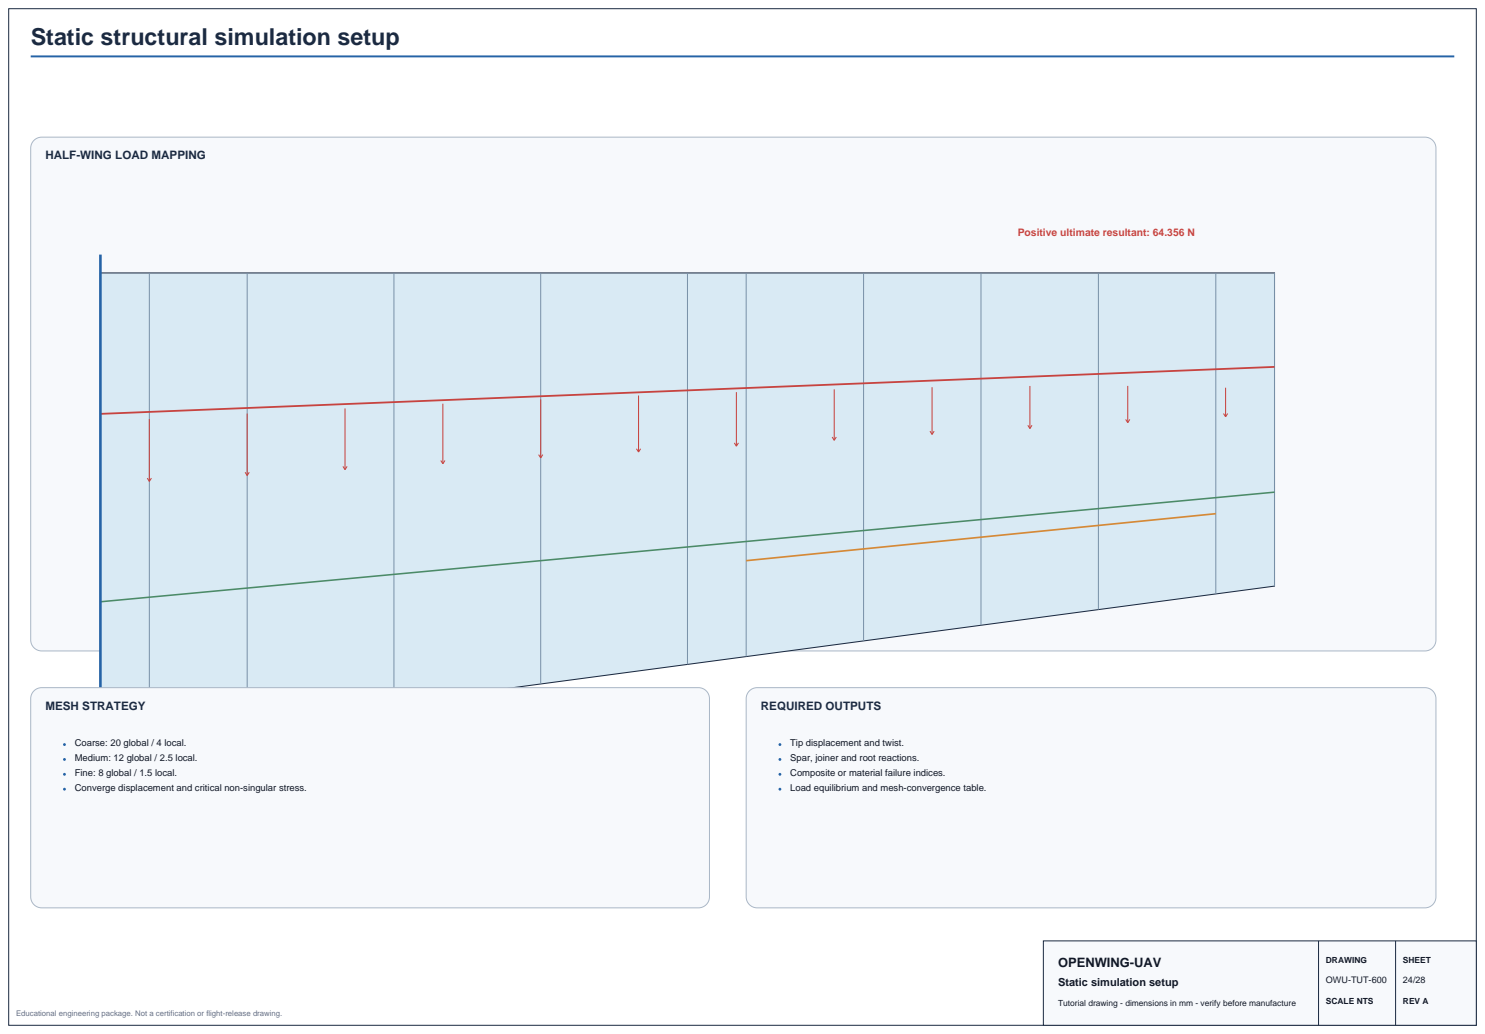
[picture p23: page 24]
MESH STRATEGY; REQUIRED OUTPUTS; DRAWING; SHEET; OWU-TUT-600

HALF-WING LOAD MAPPING

Positive ultimate resultant: 64.356 N

Coarse: 20 global / 4 local.
Medium: 12 global / 2.5 local.
Fine: 8 global / 1.5 local.
Converge displacement and critical non-singular stress.

Tip displacement and twist.
Spar, joiner and root reactions.
Composite or material failure indices.
Load equilibrium and mesh-convergence table.

Joiner + rear-pin fixture

OPENWING-UAV
Static simulation setup

# Modal, buckling and dynamic-screening setup

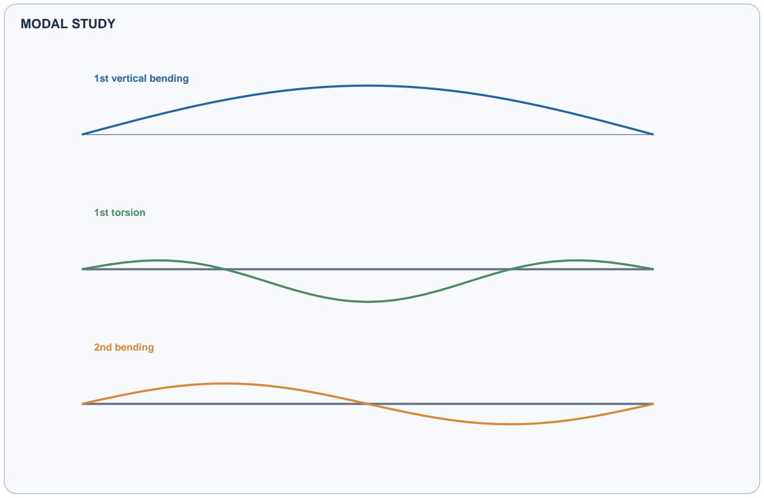
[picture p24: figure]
MODAL STUDY; 1st vertical bending; 1st torsion; 2nd bending

### BUCKLING STUDIES

Positive and negative global buckling. Upper- and lower-skin local panels.
Main- and rear-spar web local buckling.
Interpret critical load as BLF x applied load.
Use imperfections of 0.25t, 0.5t and 1.0t in nonlinear sensitivity.

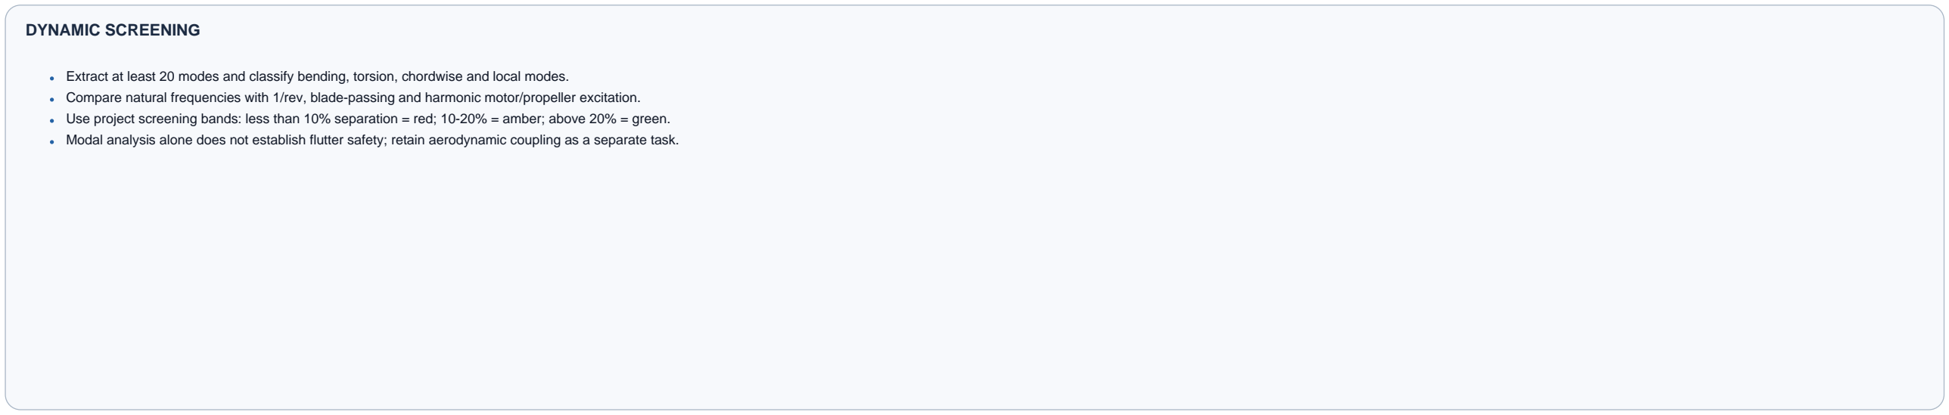
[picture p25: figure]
DYNAMIC SCREENING

Extract at least 20 modes and classify bending, torsion, chordwise and local modes.
Compare natural frequencies with 1/rev, blade-passing and harmonic motor/propeller excitation.
Use project screening bands: less than 10% separation = red; 10-20% = amber; above 20% = green. Modal analysis alone does not establish flutter safety; retain aerodynamic coupling as a separate task.

## OPENWING-UAV

Modal and buckling setup

DRAWING | SHEET
OWU-TUT-610 | 25/28

# Prototype proof-load fixture and twelve-band loading

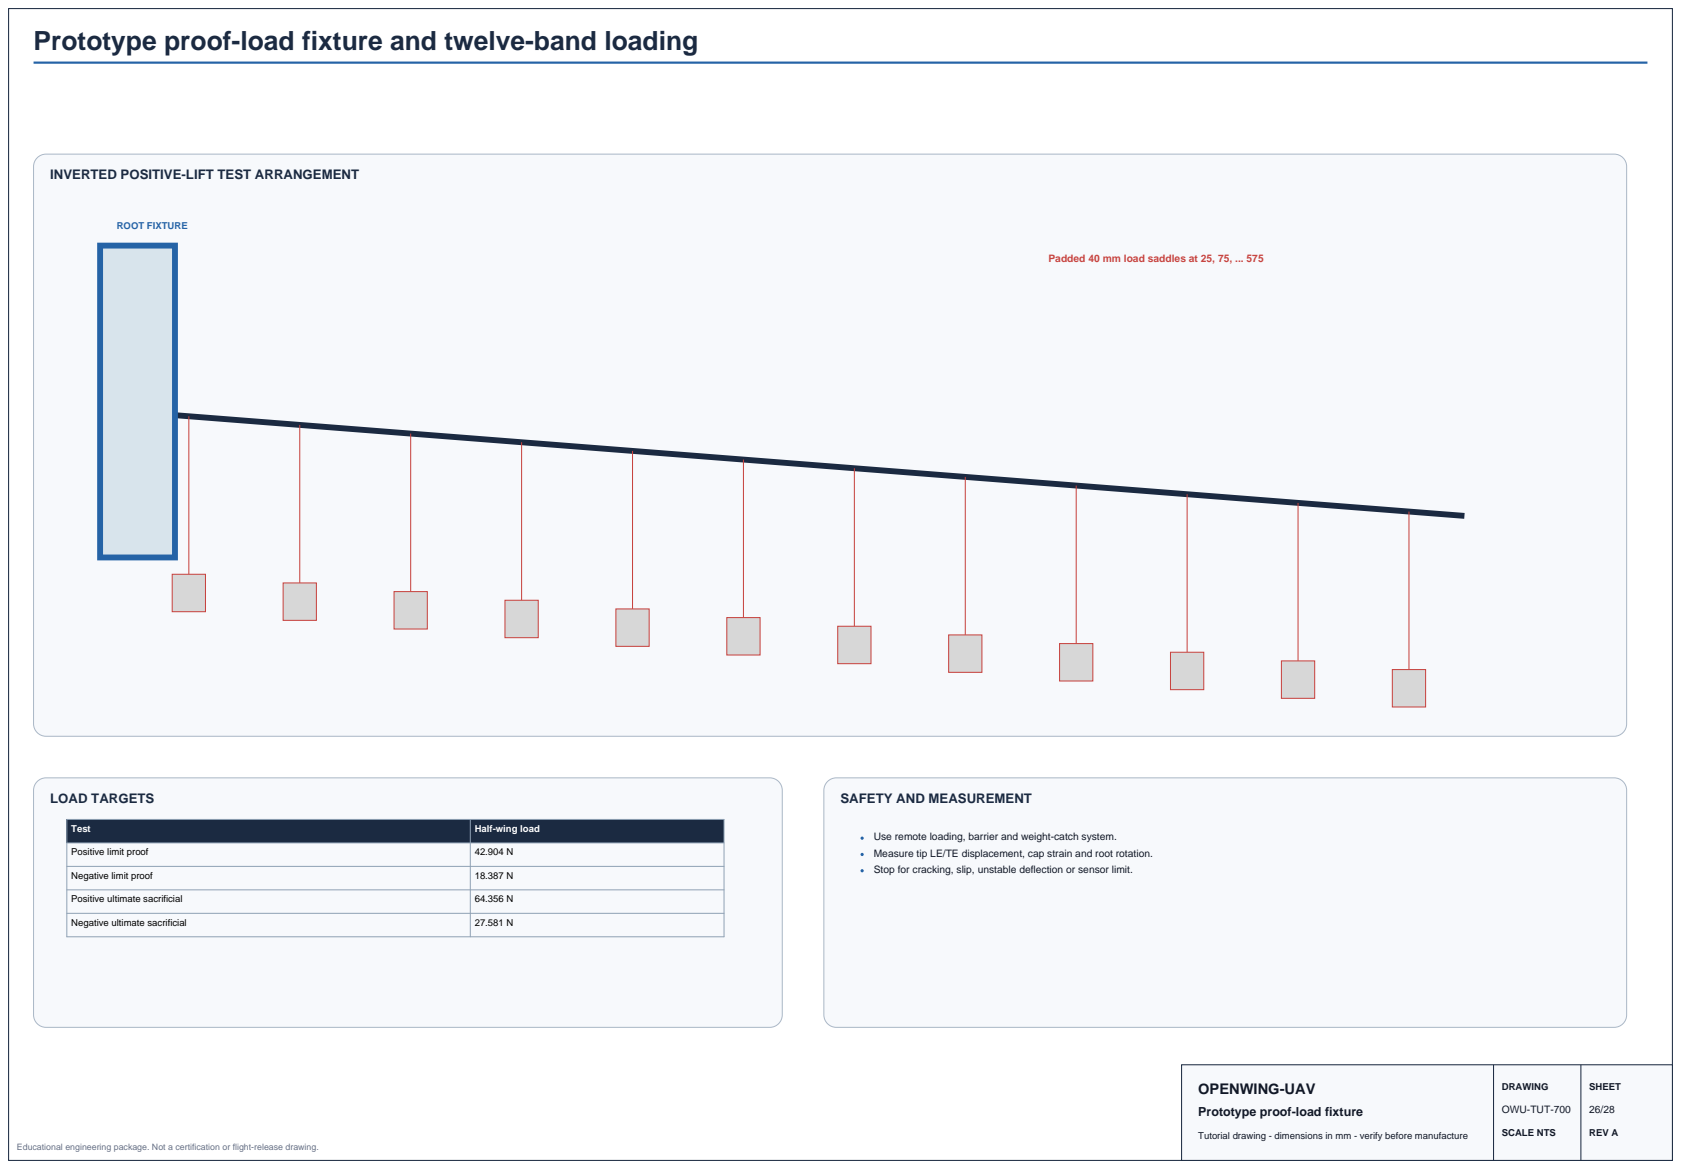
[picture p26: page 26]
ROOT FIXTURE; LOAD TARGETS; DRAWING; SHEET; OWU-TUT-700

INVERTED POSITIVE-LIFT TEST ARRANGEMENT

Padded 40 mm load saddles at 25, 75, ... 575

SAFETY AND MEASUREMENT

Test | Half-wing load

Use remote loading, barrier and weight-catch system.
Measure tip LE/TE displacement, cap strain and root rotation.
Stop for cracking, slip, unstable deflection or sensor limit.

Positive limit proof | 42.904 N

Negative limit proof | 18.387 N

Positive ultimate sacrificial | 64.356 N

Negative ultimate sacrificial | 27.581 N

OPENWING-UAV
Prototype proof-load fixture

# Manufacturing plan and bill of materials

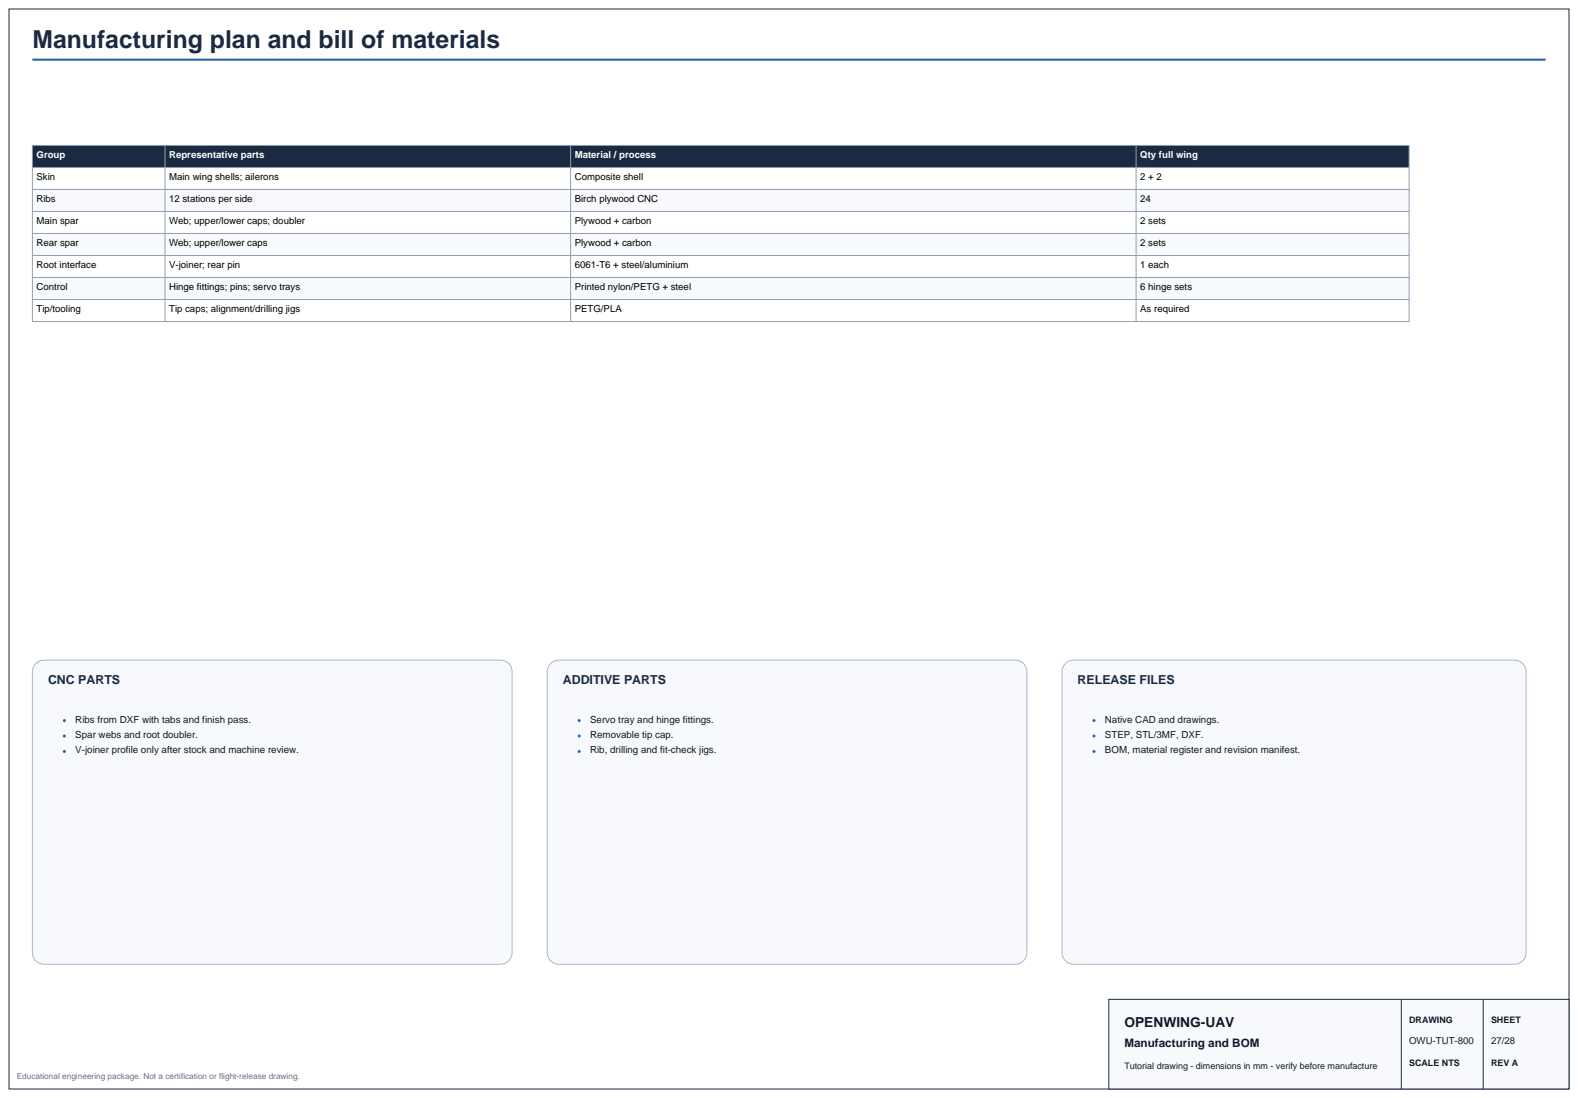
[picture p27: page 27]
CNC PARTS; ADDITIVE PARTS; RELEASE FILES; DRAWING; SHEET; OWU-TUT-800

Group | Representative parts | Material / process | Qty full wing

Skin | Main wing shells; ailerons | Composite shell | 2 + 2

Ribs | 12 stations per side | Birch plywood CNC | 24

Main spar | Web; upper/lower caps; doubler | Plywood + carbon | 2 sets

Rear spar | Web; upper/lower caps | Plywood + carbon | 2 sets

Root interface | V-joiner; rear pin | 6061-T6 + steel/aluminium | 1 each

Control | Hinge fittings; pins; servo trays | Printed nylon/PETG + steel | 6 hinge sets

Tip/tooling | Tip caps; alignment/drilling jigs | PETG/PLA | As required

Ribs from DXF with tabs and finish pass.
Spar webs and root doubler.
V-joiner profile only after stock and machine review.

Servo tray and hinge fittings.
Removable tip cap.
Rib, drilling and fit-check jigs.

Native CAD and drawings.
STEP, STL/3MF, DXF.
BOM, material register and revision manifest.

OPENWING-UAV
Manufacturing and BOM

# Final inspection, documentation and release checklist

All CAD features rebuild without errors and all external references are controlled.

Right and left wings have matching span, root interface, dihedral and control travel.

Root chord 240, tip chord 160 and semi-span 600 are verified physically.

Tip rise is 31.445 and twist progresses from 0 to -2 deg.

Main and rear spars are continuous, straight and correctly bonded.

All rib stations and thicknesses match the released drawings.

Joiner insertion is 150 per side and rear pin is correctly retained.

Servo, pushrod and aileron operate freely through +20 / -15 deg.

Wiring is protected, strain-relieved and clear of control hardware.

Surface finish is smooth; no unacceptable waviness, delamination or gaps.

Mass and centre of gravity are recorded for each half-wing.

Static, modal and buckling studies use the final mass/material configuration.

Proof-load and modal-test data are correlated with the final FEA revision.

DXF/CAM files are simulated for the actual machine before manufacture.

All released files have revision, date and SHA-256 manifest entries.

### RELEASE STATEMENT

This tutorial drawing set describes the project architecture and build sequence. Final manufacturing and flight use require verified native CAD, material data, solver results, machine-specific CAM review and physical test evidence.

## OPENWING-UAV

Inspection and release

DRAWING | SHEET
OWU-TUT-900 | 28/28

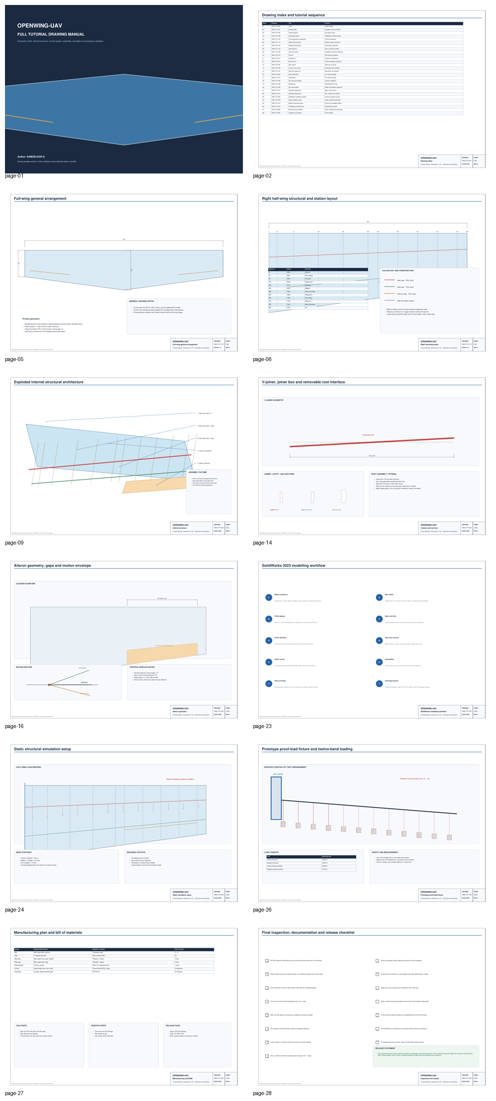
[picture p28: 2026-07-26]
assets/images/tutorial-montage.png

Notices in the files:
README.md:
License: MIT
